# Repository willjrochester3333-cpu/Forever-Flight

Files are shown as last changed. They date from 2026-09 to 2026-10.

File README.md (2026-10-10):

# Forever-Flight — FF-1 *Ember*

A 2 m span autonomous soaring glider for wildfire detection, with a
retractable motor pylon and a retractable energy-recovery turbine.

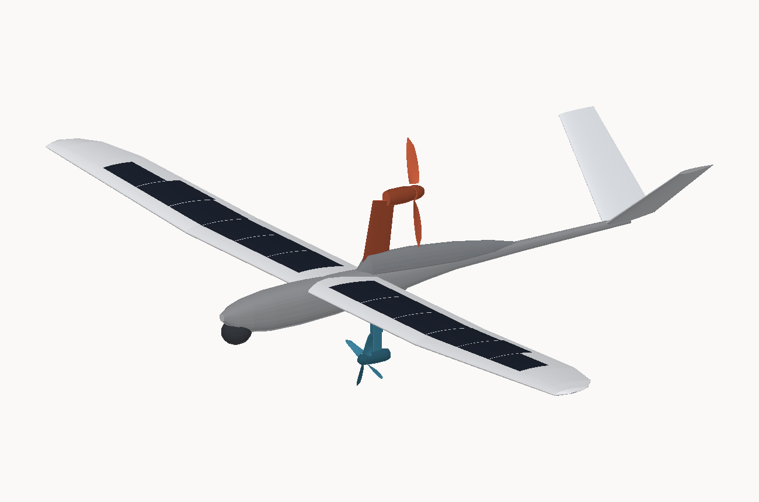
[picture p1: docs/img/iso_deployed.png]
FF-1 Ember


| | |
|---|---|
| Span | 2.00 m |
| MTOW | 1622 g |
| Best glide | L/D 17.6 at 9.5 m/s |
| Minimum sink | 0.51 m/s |
| **Endurance** | **10.0 h** (solar + thermal soaring, 38° N, August) |
| Endurance, battery only | 1.4 h |
| Survey coverage | 10.1 km²/h → 81 km² per sortie |
| Detection floor | ~0.5–1 m² of active flame, clutter-limited |

## What the dynamo actually does

It works. In steady level flight a turbine cannot pay for itself — extracting
power costs more power, and that shows up as drag. But this aircraft doesn't
fly steady level flight. **It soars: it climbs on atmospheric energy and
descends on the turbine, so the source is the air, not the pack. Over that
cycle the output is unambiguously net positive.**

The turbine takes whatever the atmosphere offers beyond what the airframe
needs to stay up. On a good day that's **3.6 W continuous —
46 % of the 7.9 W hotel load — and about
14 Wh over a flight**, a quarter of the pack.

**The catch is storage, not generation.** On a clear day the array has the
pack full by mid-morning, so all of it is spilled. The turbine pays exactly
when the array can't: with one solar string failed it's worth +0.6 h, in heavy
overcast +0.9 h, and with a badly degraded array +4.6 h. That's the argument
for any redundant system — it costs nothing on the days it isn't needed,
because it's stowed.

The deploy rule follows: **only harvest when the pack has room.** On a full
pack the surplus should go into altitude or survey coverage instead.

Full working in [docs/ANALYSIS.md](docs/ANALYSIS.md) §5.5.

## Documents

| | |
|---|---|
| [docs/DESIGN.md](docs/DESIGN.md) | The design plan — configuration, aerodynamics, structure, energy, mechanisms, autonomy, payload, flight test, risks |
| [docs/ANALYSIS.md](docs/ANALYSIS.md) | Every computed number, generated from source |
| [docs/VERTICAL_MAST.md](docs/VERTICAL_MAST.md) | VDM-1 — the telescoping vertical deployment mast and its micro linear actuator |
| [docs/ASSEMBLY.md](docs/ASSEMBLY.md) | Build manual: CG, spars, hinges, throws, balance and the first flight |
| [docs/PRINTING.md](docs/PRINTING.md) | Cutting it into 30 printable parts for a Bambu Lab A2L, and the carbon spar that runs through them |
| [docs/OPTIMISATION.md](docs/OPTIMISATION.md) | Lifting-line optimisation of the wing, and measuring the built mesh against its specification |
| [docs/EDF.md](docs/EDF.md) | The fixed 50 mm EDF installation: nozzle area, inlet lip, and what a duct costs when the fan is off |
| [docs/JETWING.md](docs/JETWING.md) | JW-1 — a swept flying wing in the Jetwing configuration, with the tailless trim solved |
| [docs/VARIANTS.md](docs/VARIANTS.md) | Airframe variants — plans-built glider and nose-motor versions at 2.0 m and 2.5 m |
| [docs/PLANS.md](docs/PLANS.md) | Printable 1:1 build plans, tiled for A4 |
| [docs/FLIGHT_ANALYSIS.md](docs/FLIGHT_ANALYSIS.md) | Flight log analysis — graphs, a fitted drag polar, and predictions from real flight data |
| [docs/BUILD_MANUAL.md](docs/BUILD_MANUAL.md) | Bill of materials and construction sequence |

## The 3D model

```
models/
  ff1_deployed.stl     both pods extended
  ff1_stowed.stl       both pods retracted
  ff1_deployed.obj     named groups, for CAD import
  ff1_stowed.obj
  geometry.json        parametric data, including the solar strip layout
  parts/*.stl          each component separately
```

The assembly STLs are **visual/assembly models**: components interpenetrate at
their joins, so the union is not a closed manifold. Boolean the parts in
Blender or Meshmixer before slicing, or print from `parts/` individually. The
wing meshes on their own are watertight.

Units are millimetres; +X aft with the nose at the origin, +Y starboard, +Z up.

## Building one

```bash
python3 tools/plans.py     # plans/FF-1_plans_A4.pdf -- 22 sheets, print at 100%
```

Full-size foam-prototype templates tiled onto A4: wing, aerofoil sections,
fuselage pod, formers, V-tail. Print at **actual size**, never "fit to page".
See [docs/PLANS.md](docs/PLANS.md).

## Analysing a real flight

```bash
python3 tools/flight_analysis.py YOURLOG.BIN --mass 1.68 --open
```

Reads an ArduPilot log or any CSV and writes an HTML report: flight trace,
measured drag polar against the design curve, energy accounting, and endurance
re-predicted on the measured drag level. See
[docs/FLIGHT_ANALYSIS.md](docs/FLIGHT_ANALYSIS.md). Try it on the bundled
synthetic flight first:

```bash
python3 tools/flight_analysis.py data/example_flight.csv
```

## Regenerating

```bash
python3 tools/build_model.py   # models/
python3 tools/analysis.py      # docs/ANALYSIS.md
python3 tools/render.py        # docs/img/
```

No dependencies — standard library only, Python 3.8+.

`tools/config.py` is the single source of truth. Change a dimension there and
the model, the drawings, the mass budget, the drag polar, the energy budget
and the detection performance all regenerate consistently.

| | |
|---|---|
| `tools/config.py` | Every dimension, mass, efficiency and mission parameter |
| `tools/airfoil.py` | NACA 4-digit generator plus the curvature-limiting "solar flattening" morph |
| `tools/mesh.py` | Triangle mesh kernel, STL and OBJ writers |
| `tools/build_model.py` | Lofted airframe, deployable pods, solar cell layout |
| `tools/analysis.py` | Drag build-up, polar, turbine physics, clear-sky solar model, mission simulation, stability, wing beam, LWIR detection |
| `tools/mast.py` | VDM-1 sizing: stroke, stage count, drive loads, actuator selection, resonance |
| `tools/spar.py` | Shear and bending moment along the span, and the carbon that carries it |
| `tools/optimise.py` | Lifting-line span loading, drag buildup, constrained search over taper, chord and washout |
| `tools/jetwing.py` | Swept flying wing: reflexed section tuned by thin-aerofoil theory, strip-theory trim and CG solve, geometry, export |
| `tools/variants.py` | Builds the plans-based variants (no retractable pods) at any geometric scale |
| `tools/plans.py` | Printable A4 build plans: tiled 1:1 templates, aerofoil sections, formers, DXF |
| `tools/pdf.py` | Minimal vector PDF writer (exact page sizes, so prints come out 1:1) |
| `tools/flightlog.py` | Log readers: ArduPilot .BIN, ArduPilot .log, or any CSV |
| `tools/flight_analysis.py` | Flight report: segmentation, drag-polar fit with bootstrap intervals, endurance re-prediction, HTML + SVG charts |
| `tools/simulate_flight.py` | Synthetic flight log, flown against the design model, for testing the analyser |
| `tools/render.py` | Z-buffered PNG renderer for the three-views |

## Status

Design study with a complete parametric model and a closed analysis. Nothing
has been built or flown. The aerofoil is a geometric mould definition, not a
validated section — see [docs/DESIGN.md](docs/DESIGN.md) §2.1 before cutting
anything.

Flying near an active wildfire without coordination with the incident
commander is dangerous and illegal in most jurisdictions — it grounds the air
tankers. See [docs/DESIGN.md](docs/DESIGN.md) §13.

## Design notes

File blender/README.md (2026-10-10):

# Planes in Blender

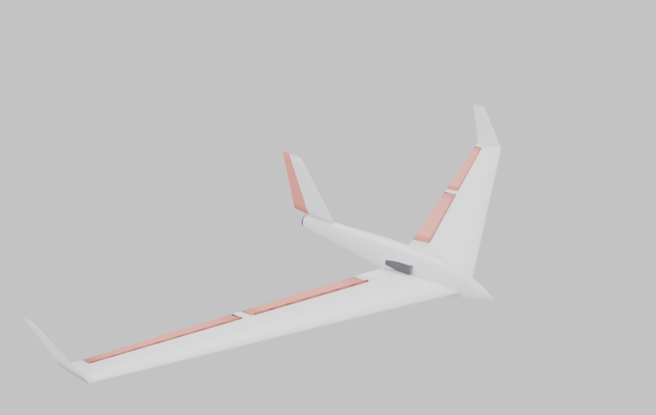
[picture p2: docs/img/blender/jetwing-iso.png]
Jetwing


```
blender/jetwing.py          the swept flying wing (2060 mm BIG WING)
blender/jetwing.blend       ready to open
blender/basic_plane.py      a simple conventional trainer
blender/basic_plane.blend
blender/render_jetwing.py   camera, lights, previews, saves the .blend
blender/render_preview.py   the same, for the trainer
```

## Running

**Any Blender version:** `blender --python blender/jetwing.py`

Opening a `.blend` directly needs **Blender 5.0+**, because the pip `bpy` that
built them is 5.0.1. On 4.x you get a version error — run the `.py` instead,
which works back to 2.8 and gives the identical model.

**No Blender at all:** `pip install bpy && python3 blender/render_jetwing.py`
(Cycles on CPU; EEVEE needs a display.)

## Working control surfaces

Four flaps and a rudder, each a separate object whose origin sits **on its
hinge line**, with the local axis running **along** that line. The hinges are
swept, so they are not parallel to any world axis — the rest frame is stored
on each object as `hinge_origin` / `hinge_basis` / `hinge_axis` (visible in
Blender's Object Properties → Custom Properties) and the deflection is
composed with it:

```python
import jetwing
jetwing.set_controls(flap=40, aileron=-32, rudder=22)   # crow brake + yaw
jetwing.set_controls(elevator=-8)                       # both pairs up
jetwing.set_controls()                                  # neutral
```

`elevator` adds to **both** pairs, which is how a flying wing gets pitch out
of surfaces that are already doing something else.

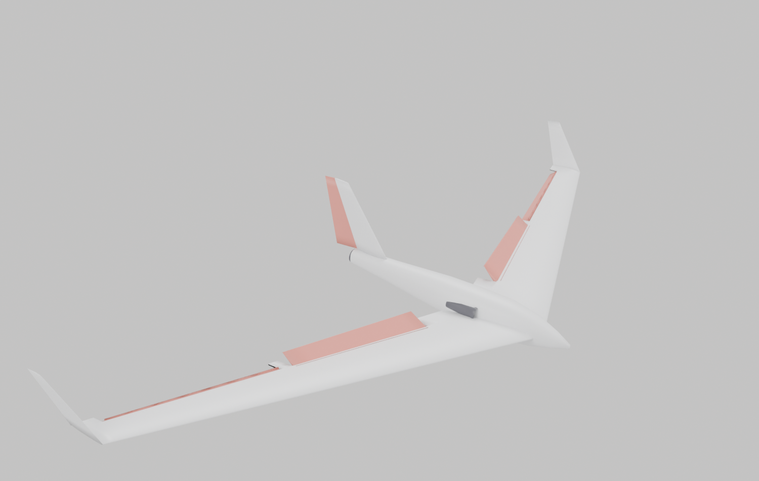
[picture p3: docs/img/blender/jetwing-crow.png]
crow


## Printing it

**`jetwing-parts.blend` — open this one for the parts.** All 30 pieces, each
standing in its print orientation on z = 0, laid out on a grid and labelled
with its name and size, plus an A2L build volume drawn to one side for scale.
The assembled aircraft is in an `Assembled` collection, hidden; tick it back
on in the Outliner to see it whole.

To get a single part out: select it, **File > Export > STL**, tick *Selection
Only*. Or skip Blender entirely and use the ready-made STLs in `print/`.

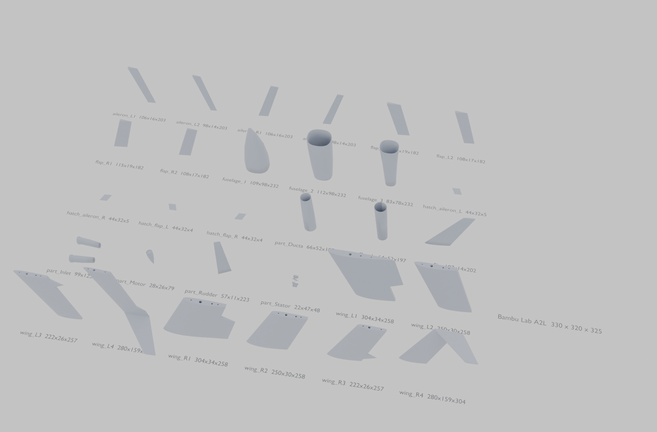
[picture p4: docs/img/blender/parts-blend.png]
parts


`blender/print_parts.py` is what cuts the aircraft into **30 parts, all inside
a Bambu Lab A2L's 330 x 320 x 325 mm and all watertight**, bores the stepped
spar channel, the servo bays, the pushrod guides, the swept loom channel and
the joint dowel holes, and writes `print/*.stl`.

`blender/check_parts.py` then loads every STL back in and audits it: positive
volume, no non-manifold edges, and **no self-intersecting faces**. Run it
before you print. That last test is there because an exact boolean on a
self-intersecting target returns something plausible rather than an error --
it once returned the cutter in place of the part, and a 6 mm tube is
watertight, fits the bed and slices.

See [docs/PRINTING.md](../docs/PRINTING.md) for the carbon sizes and the
assembly order.

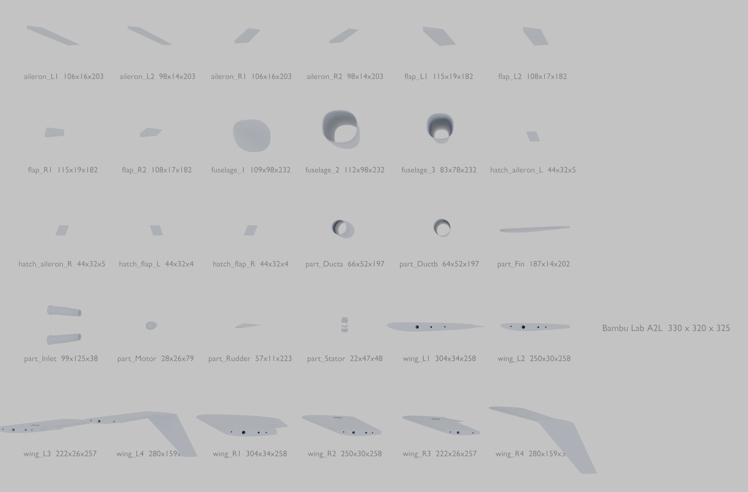
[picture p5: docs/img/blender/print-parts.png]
parts


## Dimensions, and checking them

`blender/measure.py` measures the **evaluated mesh, after modifiers, in world
space** and compares it with the specification, exiting non-zero if anything
is out. `blender/render_dims.py` draws the dimensions onto a plan view, reading
them off the measured geometry rather than off the parameters -- so if the two
ever disagree, the drawing shows the truth.

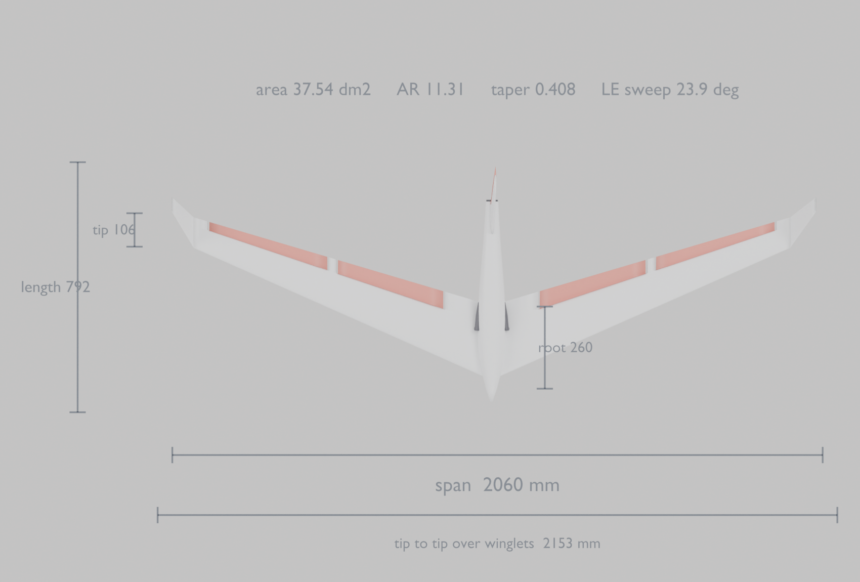
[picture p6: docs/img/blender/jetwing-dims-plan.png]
dimensions


Tip chord and washout are outputs of `tools/optimise.py`, which solves the
span loading by lifting-line theory. See [docs/OPTIMISATION.md](../docs/OPTIMISATION.md).

## The EDF

Fixed 50 mm unit, fully faired, nothing retracting: bellmouth inlets with a
3.1 mm lip radius, a 1.2 deg diffuser, a 12-blade rotor, a 7-vane stator to
take the swirl back out, motor can with a closing tailcone, and a 40.5 mm
converging nozzle. Sizing and the reasoning are in
[docs/EDF.md](../docs/EDF.md); every dimension is an output of
`tools/edf.py`.

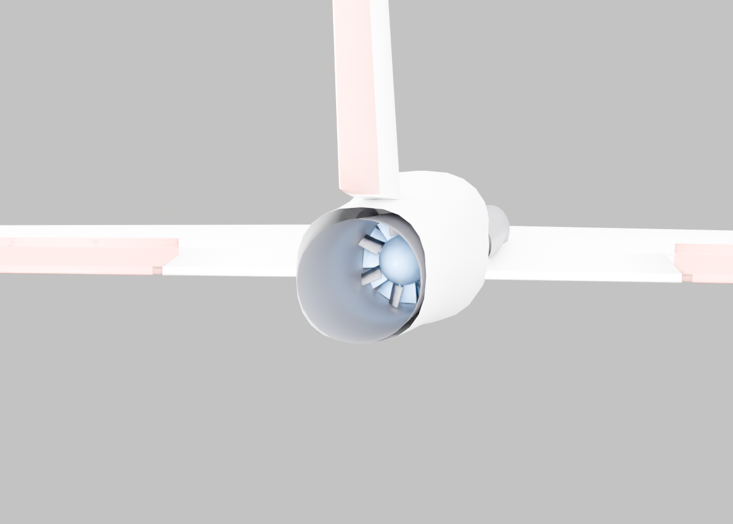
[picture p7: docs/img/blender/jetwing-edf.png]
EDF


## What is copied and what is not

planeprint.com and the mirror of its assembly manual are both blocked by this
session's network policy, so no geometry file was ever available. These
figures are from the published specification, which search did reach:

| | |
|---|---|
| span | 1270 mm standard / **2060 mm BIG WING** ← built here |
| flight weight | 860–1750 g |
| wing loading | 28–48 g/dm² |
| power | EDF 70 mm on 4S, or glider |
| channels | 4/6, **four flaps**, butterfly/crow |
| variants | with or without a steerable rudder; the rudder version has *"integrated vector control"* |
| printing | 200 mm cube, LW-PLA + PLA |

Wing **area** is not published. 36.5 dm² is chosen because it is the one value
that makes all four published numbers land exactly:

```
1022 g -> 28.0 g/dm2        1750 g -> 48.0 g/dm2
```

and it lets both wings share one 260 mm root chord, which a modular kit with a
common fuselage joint has to do.

**Sweep, taper, aerofoil and CG are published nowhere.** Those are designed
from the aerodynamics — a reflexed section with washout so the wing trims
itself without a tailplane — not copied. So this is a faithful model, not a
replica. Real dimensions go straight into the `P` dictionary at the top of
`jetwing.py`.

## Structure

Everything is lofted from parametric sections, so the shape is in the maths
rather than in vertex soup:

| | |
|---|---|
| `section()` | NACA 4-digit camber + a trailing-edge reflex term |
| `chord_at` / `le_at` / `twist_at` | planform and washout at any station |
| `place()` | puts a unit-chord section into 3D at a spanwise station |
| `datum()` | one rotation applied to **vertices**, so fuselage, duct and fin share a frame |
| `hinge_frame()` | world position and axes of a swept hinge line |

`datum()` being applied to vertices rather than to objects is deliberate: a
rotated pod and an unrotated fin drift apart and the fin ends up floating in
mid-air, which is exactly what the first attempt did.

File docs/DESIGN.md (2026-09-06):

# FF-1 *Ember* — design plan

A 2 m span autonomous soaring glider for wildfire detection, with a retractable
motor pylon and a retractable energy-recovery turbine.

Every number quoted here is computed by `tools/analysis.py` from
`tools/config.py`. The full working is in [ANALYSIS.md](ANALYSIS.md).

---

## 0. Read this first — what the dynamo actually does

The brief asks for a turbine-driven dynamo that charges the aircraft to
increase flight time. **It does, and the energy is genuinely free. The
limitation is not generation — it is that on a good day there is nowhere to
put it.**

**Where the energy comes from.** In steady level flight a turbine cannot pay
for itself: extracting P watts costs P/(η_gen·η_rect) watts of shaft power,
and that shaft power is drag. But this aircraft does not fly steady level
flight. It soars. It climbs on atmospheric energy and descends on the turbine,
and across that cycle the source is the air, not the pack. **Over a soaring
cycle the output is unambiguously net positive.**

The sustainable harvest is what the atmosphere offers *beyond* what the
airframe needs to stay up:

```
    c_net = f·(w − s_circle) − (1 − f)·s_glide(v)      net specific climb
    P_surplus = W · c_net                              shaft watts the turbine can take
```

On a good day (3.2 m/s thermals, in usable lift 42 % of the time) that comes
to **3.6 W continuous — 46 % of the
7.9 W hotel load — and about 14 Wh over a
flight, a quarter of the pack's nameplate capacity.** In weaker British
conditions it is 1.3 W. The optimum descent speed is
14 m/s, not the 20–25 m/s the turbine's raw power curve suggests:
rotor power goes as V³, but so does airframe drag, and past about 15 m/s the
airframe eats the surplus faster than the rotor can take it.

**The catch is storage, not generation.**

| Array output | Condition | Turbine off | Turbine on | Gain | Harvest spilled |
|---|---|---|---|---|---|
| 100 % | clear sky, clean array | 10.07 h | 10.07 h | **+0.00 h** | 100 % |
| 55 % | thin overcast | 9.88 h | 9.90 h | **+0.02 h** | 74 % |
| 40 % | one of three strings failed | 9.10 h | 9.71 h | **+0.61 h** | 0 % |
| 30 % | heavy overcast | 7.98 h | 8.86 h | **+0.87 h** | 0 % |
| 20 % | array badly degraded | 2.56 h | 7.18 h | **+4.62 h** | 0 % |

On a clear day the array has the pack full by mid-morning, so **every watt-hour
the turbine makes is spilled**. The energy is real; the tank is full. The
turbine pays exactly when the array cannot — overcast, soiling, a failed
string, low winter sun — and in that band it is worth **hours**.

That is a better reason to carry it than a daily contribution would be. It is
the argument for any redundant system: it costs nothing on the days it is not
needed, because it is stowed. Three jobs:

| Mode | When | Value |
|---|---|---|
| **A — surplus harvesting** | Soaring with lift to spare | 1.3–3.6 W sustained, spilled when the pack is full |
| **B — regenerative descent** | Any commanded descent | Replaces the spoilers the wing would otherwise need |
| **C — emergency power** | Pack or array failure | 8.1 W at 15 m/s against a 7.9 W hotel load — keeps the autopilot and radio alive all the way down |

The deploy rule follows directly, and it is already in §6.1: **only harvest
when the pack has room.** On a full pack the surplus should go into altitude
or airspeed — banked as potential energy, or spent on survey coverage — not
into a turbine with nowhere to send it.

**The eight hours still come mostly from somewhere else.** Solar plus
autonomous thermal soaring gives 10.1 hours. On batteries
alone this aircraft flies for 1.5 hours. The turbine is the margin that makes
a bad day survivable, not the primary mechanism.

---

## 1. Configuration

isometric, pods deployed

Pod-and-boom fuselage, shoulder-mounted three-panel wing, V-tail. Both
deployable pods retract into the fuselage: the motor pylon folds aft into a
dorsal spine, the turbine arm folds forward under the keel.

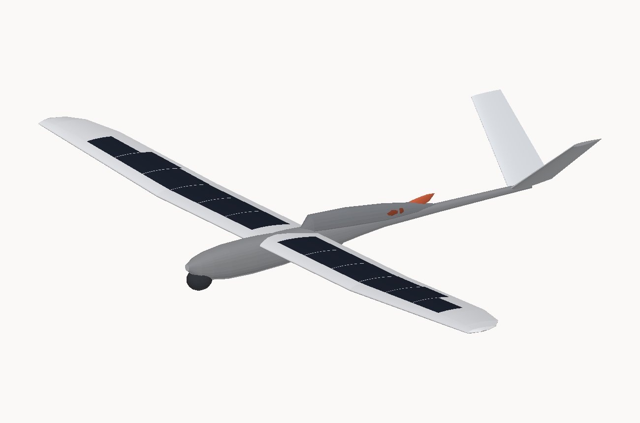
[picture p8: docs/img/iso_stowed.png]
isometric, pods stowed


*Stowed: a clean sailplane. This is the configuration it spends most of the
mission in.*

| | |
|---|---|
| Span | 2.00 m |
| Wing area | 0.3580 m² |
| Aspect ratio | 11.17 |
| Mean aerodynamic chord | 181.8 mm |
| Length overall | 1.19 m |
| MTOW | 1622 g |
| Wing loading | 44.4 N/m² (4.53 kg/m²) |
| Aerofoil | FF-SC1, 9.48 % thick, 2.76 % camber — a solar-flattened SD7037-class section |
| Best glide | **L/D 17.6 at 9.5 m/s** |
| Minimum sink | **0.51 m/s at 9.0 m/s** |
| Stall | 7.79 m/s clean, 7.00 m/s with flap |
| Powered cruise | 16.7 W electrical at 9.5 m/s |
| Climb | 89 W electrical for 2.5 m/s |
| Endurance | 10.0 h (38° N, August), 1.4 h on batteries alone |
| Survey coverage | 10.1 km²/h with 30 % sidelap; 81 km² per sortie |

### 1.1 Why this layout

**Shoulder wing, constant-chord centre panel.** The centre 900 mm is untapered
at 195 mm chord. This is not aerodynamics, it is solar packing: three 41.7 mm
cell strips need 125 mm of usable chord, and only a chord of 179 mm or more
provides it once the leading-edge curvature and the thin trailing edge are
excluded. Outboard of the break the chord tapers to 92 mm and the array drops
to two strips wide.

**V-tail at 38° dihedral.** Two surfaces instead of three saves mass and
wetted area, and — the reason that actually decided it — it keeps the tail
volume out of the way of the deployed turbine's wake and gives the folded
pylon somewhere to go without a fin root in the middle of it. Tail volumes
land at V_h 0.55 and V_v 0.031, both comfortably conventional.

**Sensor turret slung under the nose, not on it.** A ventral ball at
x = 40 mm keeps the fuselage nose free and gives the thermal core a clean
nadir view with no propeller in front of it. It also means Variant N (§8) is
geometrically available.

**Pusher prop on the pylon.** The prop disc sits 79 mm aft of the wing root
trailing edge and 36 mm above the boom at its lowest point. A tractor
installation at the same pylon height would put the blade tips into the wing
trailing edge.

### 1.2 Three-view

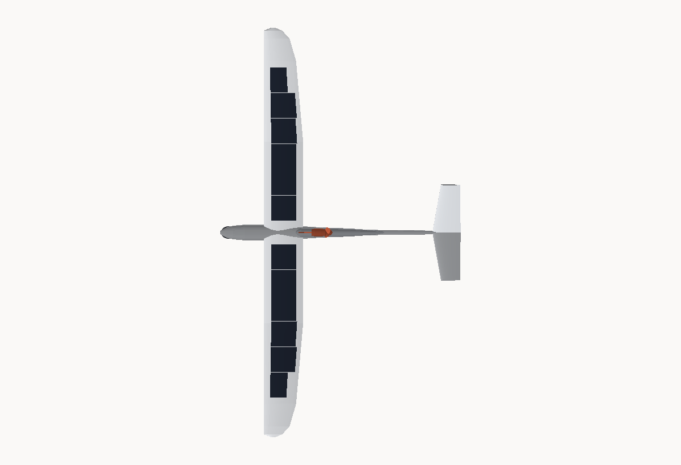
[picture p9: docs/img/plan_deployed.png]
plan

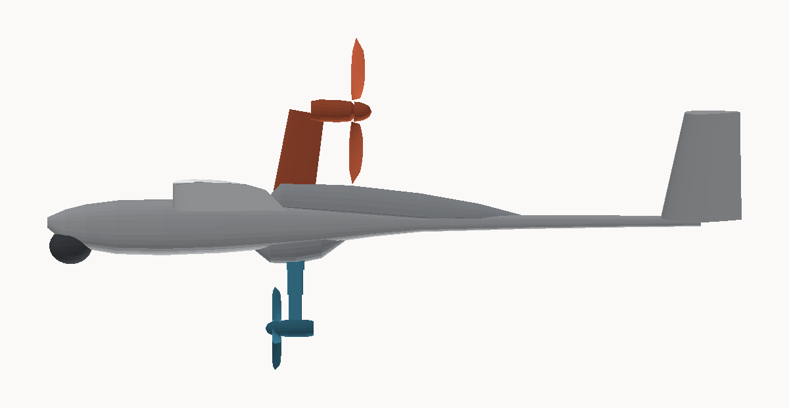
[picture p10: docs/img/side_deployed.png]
side, deployed

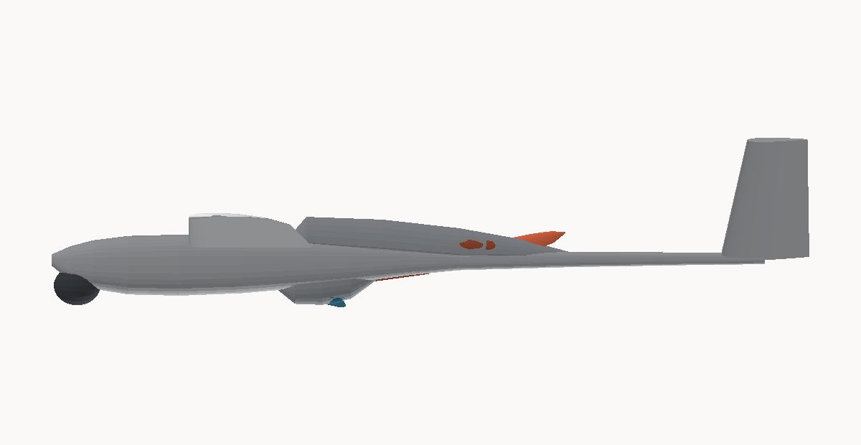
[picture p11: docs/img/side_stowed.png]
side, stowed

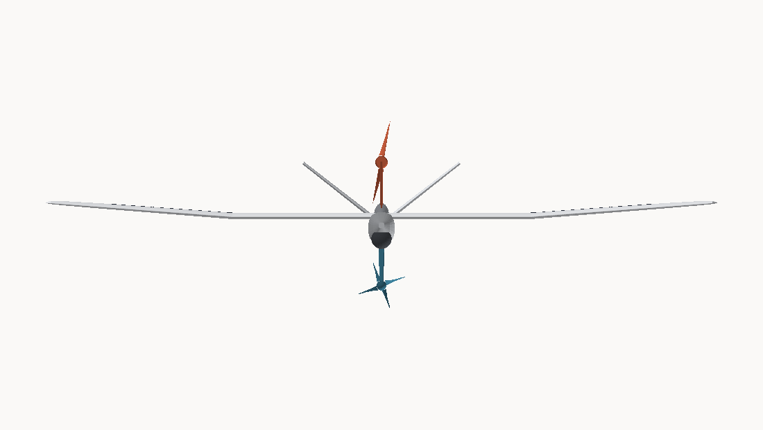
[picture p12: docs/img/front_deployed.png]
front


---

## 2. Aerodynamics

### 2.1 The aerofoil problem

Two requirements fight each other. A good low-Reynolds section at Re ≈ 110 000
wants generous upper-surface curvature to keep the laminar separation bubble
short. A monocrystalline solar cell wants to be flat, because bending it
cracks it.

The resolution is a **curvature-limited morph**. Start from a cambered base
section, then relax the upper surface between 19 % and 90 % chord until the
local radius everywhere exceeds 400 mm. `tools/airfoil.py` does this by
clamped Laplacian smoothing, which can only ever reduce curvature, so it
converges monotonically.

The result, FF-SC1, is 9.48 % thick at 28.1 % chord with 2.76 % camber at
44.8 % — geometrically very close to SD7037 (9.2 % / 2.6 %), which is a good
sign, because SD7037 is a known-good section in exactly this Reynolds range.
The flattening costs about 0.5 points of thickness and 0.2 points of camber
against the unmorphed base.

At R = 400 mm a 165 µm cell sees 0.021 % bending strain, roughly a factor of
seven below the fracture strain of cut monocrystalline silicon.

> **This is a mould definition, not a validated aerofoil.** FF-SC1 exists so
> the 3D model and the plug have exact geometry. Before cutting a mould, put
> SD7037 (or an AG40-series section) through the same morph, run it in
> XFOIL/XFLR5 at Re 90k–160k with N_crit 9, and confirm the drag bucket
> covers C_L 0.4–1.1. Drop the .dat file in `airfoils/`, point
> `WING["airfoil"]["dat_file"]` at it, and the whole model regenerates on the
> real section.

### 2.2 Drag

C_D0 = **0.0247** with both pods stowed, from a component build-up with a
15 % uncertainty margin. The wing profile is 45 % of it; the fuselage, tail
and the two bay fairings make up most of the rest.

Two entries deserve attention because they are self-inflicted:

- **Solar cell steps, 0.0012.** Cell edges and bus ribbons under the
  encapsulation are a surface-roughness penalty on the most important 70 % of
  the wing's upper surface. Flush-bonding the cells into a recess in the skin
  rather than laying them on top is worth roughly half of this.
- **The dorsal spine, 0.0011.** This is the permanent cost of being able to
  swallow the pylon. It is paid on every second of the flight, deployed or not.

At soaring C_L induced drag is 60 % of the total, so parasite-drag increments
are diluted. That is why deploying both pods only costs 6.7 % in sink rate
(§8) — much less than intuition suggests.

### 2.3 Reynolds number

Re at the MAC runs 91 000 at the stall to 180 000 at 15 m/s. This is the
regime where surface finish and transition behaviour decide the drag, not the
planform. Practical consequences:

- Wet-sand and polish the moulded surfaces. A 0.1 mm step at 20 % chord is
  worth more drag than a badly chosen taper ratio.
- Plan for **turbulator tape** at roughly 55–60 % chord on the lower surface
  if flight test shows a drag bucket that is narrower than XFOIL predicts.
  Leave the position to flight test; do not mould it in.
- Do not chase aspect ratio past about 12. The chord gets short, Re falls, and
  section drag rises faster than induced drag falls.

---

## 3. Structure

Carbon/foam wing, moulded pod, tapered carbon boom.

| | |
|---|---|
| Limit load factor | 5 g (ultimate 7.5 g) |
| Root bending moment | 16.9 N·m |
| Spar caps | 9 mm wide, 3 plies of 115 g/m² UD carbon at the root, dropped to 1 ply at 70 % semi-span |
| Root cap stress at limit | 343 MPa (≈ 700 MPa allowable, T700 UD) |
| Root EI | 51 N·m² |
| Tip deflection | 18 mm at 1 g, 91 mm at limit |

**The wing is stiffness-driven, not strength-driven.** The cap laminate is set
by wanting a flat, unstressed array — a flexing wing cracks cells and works
encapsulation seams open — long before it is set by stress. Do not thin the
caps to save the 30 g the stress margin appears to allow.

Wing construction, root to tip:

1. **D-box**: 45/45 biaxial carbon over the leading edge, wrapping to the spar.
   This carries the torsion, which matters because the array's mass is
   distributed and aft of the shear centre.
2. **Spar**: UD caps top and bottom at 30 % chord, separated by a vertical
   shear web of 45/45 glass. Caps are stepped, not tapered by sanding.
3. **Core**: 60 kg/m³ extruded polystyrene or Rohacell, hot-wire cut to the
   FF-SC1 section, relieved for the cell recesses.
4. **Skin**: 25 g/m² glass over the core aft of the spar, then the cell array,
   then the ETFE encapsulation as the outermost layer.
5. **Joiner**: 12 mm pultruded carbon tube in an aluminium sleeve at the
   centre-panel joints, with an anti-rotation pin 40 mm aft.

The three-panel wing exists so the aircraft fits in a 1.1 m case. The centre
panel carries the spar box and both bay structures; the outer panels are plugs.

---

## 4. Energy system

```
   solar array ── 3 strings ──► 3-channel MPPT ──┐
   (34 strips, 11.33 cells)                      │
                                                 ├──► 12 V bus ──► BMS ──► 3S1P 21700
   turbine ──► FOC regen controller ─────────────┤                        (52.8 Wh)
   (150 mm, 4 folding blades)                    │
                                                 └──► 5 V / 3.3 V rails ──► avionics,
   motor ◄── bidirectional ESC ◄──────────────────────                      payload
```

### 4.1 Array

34 strips (11.33 full-cell equivalents) on the wing, 1771 cm² of active cell,
**39.8 W nameplate at STC**. Cells are cut into thirds so the 125 mm dimension
runs *spanwise* — the only curvature a strip has to follow is the 41.7 mm
chordwise one, which is what §2.1 was for.

Installed chain efficiency is **15.5 %**, from 22.5 % cell efficiency after
encapsulation transmission (0.94), cell temperature (0.94), mismatch and
soiling (0.95), MPPT (0.955) and attitude/heading cosine losses (0.86). That
gives 27.5 W at 1000 W/m² on a horizontal wing, peaking around 29.6 W in
flight.

**Three independent strings on three MPPT channels**, not one. A banked turn
puts one wing panel into a different irradiance from the other; with a single
series string the shaded cells drag the whole array down to their current.
Bypass diodes every 7 strips as well.

A V-tail sub-array (+7.0 W STC) is laid out in the model but deliberately
**excluded from the energy budget** — the panels sit at 38° dihedral, their
cosine losses are much worse, and the budget closes without them. Treat it as
a growth item.

### 4.2 Pack

3S1P 21700, 52.8 Wh nameplate, **38.9 Wh usable** after 85 % depth of
discharge and a 6 Wh approach reserve.

Cell selection is set by the **climb** case, not by capacity: 89 W at 11.1 V
is 8.0 A, so cells must be rated ≥ 10 A continuous. The tempting
high-capacity, low-current 21700s are the wrong part — take the 5.0 Ah /
25 A cell over the 5.0 Ah / 7 A one.

### 4.3 Loads

Hotel load is **7.9 W**; powered cruise adds 15.1 W. So on the ground the
avionics and payload are 34 % of the powered demand and 100 % of the soaring
demand.

**On this aircraft a watt saved in avionics is worth more than a drag count.**
Concretely: duty-cycling the edge compute from 50 % to 25 % saves 1.2 W, which
is worth more endurance than a 15 % reduction in C_D0. Design the detection
pipeline around that — wake the compute board on a hardware threshold from the
thermal core, do not run inference continuously.

---

## 5. Motor installation

| | |
|---|---|
| Type | Retractable dorsal pylon, pusher |
| Pivot | x = 400 mm, on the fuselage deck |
| Pylon | 190 mm, 74 mm chord, 12 % symmetric section |
| Deployed | 80° from the deck; hub at x = 489 mm, z = +197 mm |
| Stowed | 5°; nacelle and folded blades lie in the dorsal spine to x = 772 mm |
| Motor | Outrunner, ~500 Kv on 3S, 52 g |
| Prop | 10 × 6 folding, 254 mm |
| Deployment penalty | ΔC_D0 0.0025 |

**Mechanism.** A four-bar linkage driven by a metal-gear micro servo through a
3:1 bellcrank, with an **over-centre lock at full deployment** so that in
flight the aerodynamic and thrust loads are reacted by the linkage geometry
and not by the servo. Deployment takes about 1.2 s. Bay doors are cammed off
the linkage itself — no second servo, and the doors cannot be open when the
pylon is not.

**Clearances** (verified by `tools/build_model.py`, which will refuse to
produce a model that violates them):
- Prop disc 79 mm aft of the wing root trailing edge.
- Lowest blade tip 36 mm above the boom.
- Stowed blades end at x = 772 mm; the spine runs to x = 820 mm.

**Thrust line** is 197 mm above the datum and slightly above the drag line, so
power-on pitches the nose down a little. 1.5° of down-thrust is built in to
reduce the trim change; expect to fine-tune this on the first flights.

---

## 6. Energy-recovery turbine

| | |
|---|---|
| Rotor | 150 mm, 4 folding blades, solidity 0.31 |
| Design point | λ = 2.5, C_p 0.36 |
| Generator | Low-Kv outrunner, ~380 Kv, 44 g |
| Controller | Field-oriented regen controller into the 12 V bus |
| **Mounting** | **VDM-1 vertical telescoping mast** — see [VERTICAL_MAST.md](VERTICAL_MAST.md) |
| Station | x = 425 mm, on the wing trailing-edge bulkhead |
| Stroke | 128 mm straight down, from 42.7 mm of micro-linear-actuator travel |
| Deployed | Nacelle at z = −175 mm; disc from −100 to −250 mm |
| Output | 8.1 W at 15 m/s, 19.3 W at 20 m/s, 37.7 W at 25 m/s |
| Deployment penalty | ΔC_D0 0.0033, plus the extraction drag |

**The rotor was resized during design.** A 110 mm rotor produced 1.3 W at
cruise speed and was not worth carrying. Power goes as R² and as V³, so the
fix was a bigger rotor and a rule that it only runs fast. Folding blades let a
150 mm rotor stow in a shallow ventral bay.

**The mounting changed too.** The original swing arm moved the pod 157 mm aft
on deployment, shifting the CG +12.9 mm — 7.1 % of mean chord, taking static
margin from 20 % down to 13 % at the moment the turbine extends. A mast that
only translates vertically shifts it by nothing, keeps the rotor axis aligned
with the flow through the whole travel, and makes deployment depth a
continuous variable. It costs +90 g and 3.4 % of sink rate. The full sizing,
including why 128 mm of travel has to telescope to fit inside a 73 mm deep
fuselage, is in [VERTICAL_MAST.md](VERTICAL_MAST.md).

### 6.1 Control law

This is the part that keeps the turbine from being a net loss. The turbine may
engage **only** when one of these is true:

```
A.  ceiling_hold:   altitude ≥ soar_ceiling
                AND vario_filtered ≥ 2.5 m/s
                AND airspeed ≥ 16 m/s

B.  regen_descent:  descent commanded by the mission planner
                AND altitude ≥ 150 m AGL
                AND state_of_charge < 92 %

C.  emergency:      bus_voltage < 10.2 V  OR  mppt_fault  OR  pack_fault
```

and it must disengage, and the arm must retract, when **any** of these is true:

```
    altitude < 25 m AGL          (mandatory — the rotor hangs 216 mm below
                                  the keel and there is no landing gear)
    airspeed < 14 m/s            (below this it costs more than it makes)
    state_of_charge > 97 %
    bank angle > 45° for > 3 s   (asymmetric inflow, blade root loads)
    any deployment fault
    airspeed > 20 m/s            (mast load limit -- see VERTICAL_MAST.md §7)
```

Implement the interlocks in the flight controller's Lua scripting layer, and
implement the 25 m AGL retract **as a hardware failsafe as well** — a servo
release on a discrete output, independent of the scripting engine.

### 6.2 What it actually returns

| Day | Thermal | In lift | Sustainable harvest |
|---|---|---|---|
| Weak, N. Europe | 2.2 m/s | 34 % | 1.3 W |
| Good, S. Europe | 3.2 m/s | 42 % | 3.6 W |
| Strong | 4.0 m/s | 45 % | 5.2 W |

Full grid in [ANALYSIS.md](ANALYSIS.md) §5.5. Two things fall out of it that
are not obvious:

**On good days the rotor is the limit, not the atmosphere.** A 150 mm rotor
cannot absorb everything a strong day offers at the optimum descent speed.
Going to 175 mm buys about 0.7 W more harvest and 3 W more in Mode C, at the
cost of 18 mm more mast stroke (146 mm instead of 128) and the mass that comes
with it. The baseline stays at 150 mm because the extra is only available on
days when the pack is full anyway — but if the aircraft is ever re-scoped for
overcast operation, size the rotor up.

**Descend slowly.** The optimum is 14 m/s. Diving at 25 m/s
extracts more instantaneous power but wastes far more of the surplus in
airframe drag, and it burns the altitude band faster.

## 7. Avionics and autonomy

| Function | Specification |
|---|---|
| Flight controller | ArduPlane on an F405/H743-class wing board, with airspeed and a good baro |
| Soaring | **ArduSoar** (`SOAR_ENABLE`), variometer-based thermal detection with Reichmann centring on an EKF thermal estimate |
| Navigation | GNSS with SBAS, magnetometer, airspeed (essential — the soaring controller needs energy rate, not just baro) |
| Link | 868/915 MHz LoRa telemetry for BVLOS command and hotspot reporting; a 2.4 GHz control link for the test phase |
| Payload compute | Low-power SBC, event-triggered, not free-running |

**Autonomous thermal soaring is not optional here.** The 8-hour requirement
closes on solar alone in good conditions, but the margin that absorbs a hazy
day, a cool morning or a dirty array comes from thermals. ArduSoar is mature,
in-tree and flight-proven on aircraft of this class; use it rather than
writing a soaring controller.

Key parameters to set: `SOAR_VSPEED` (climb rate to trigger thermalling — start
at 0.7 m/s), `SOAR_ALT_MIN` / `SOAR_ALT_MAX` for the soaring band (250–900 m
here), and `SOAR_POLAR_*` for the sink polar in §2 so the speed-to-fly logic
is right.

The survey pattern and the soaring controller must share an altitude budget.
The sensible architecture is: fly the survey lawnmower pattern as the default,
let ArduSoar interrupt it to climb when it finds lift, and resume the pattern
at the interruption point. Do not try to soar and survey simultaneously —
banking hard in a thermal wrecks the sensor geometry anyway.

---

## 8. Wildfire payload

| | |
|---|---|
| Thermal | LWIR radiometric microbolometer, 160 × 120, 57° HFOV, 50 mK NETD, 8–14 µm |
| Visible | Rolling-shutter module for smoke-plume cross-checking and geolocation |
| Survey altitude | 400 m AGL |
| Ground swath | 434 m |
| Ground sample distance | 2.71 m/pixel (7.4 m² per pixel) |
| Coverage | 10.4 km²/h with 30 % sidelap → **83 km² per 8 h sortie** |

### 8.1 Sub-pixel detection

A fire much smaller than one pixel still raises that pixel's apparent
temperature, because radiant exitance goes as T⁴. Computed properly — with the
Planck integral over the 8–14 µm band, which captures only 17 % of an 800 K
flame's emission against 38 % of the background's, so LWIR is the
*unfavourable* band here:

| Flame area | Pixel fill | Apparent pixel T | ΔT | ΔT / NETD |
|---|---|---|---|---|
| 0.05 m² | 0.7 % | 36.1 °C | +9.1 K | 182× |
| 0.10 m² | 1.4 % | 44.5 °C | +17.5 K | 350× |
| 0.50 m² | 6.8 % | 98.3 °C | +71.3 K | 1425× |
| 1.00 m² | 13.6 % | 148.9 °C | +121.9 K | 2437× |
| 4.00 m² | 54.3 % | 353.3 °C | +326.3 K | 6527× |

**The sensor is not the limit — clutter is.** Sun-baked rock, dark soil and
asphalt reach 55–70 °C on a summer afternoon, which is +28 to +43 K. Anything
below that is indistinguishable from hot ground in a single frame. The
realistic single-frame detection floor is **0.5–1 m² of active flame**, not
the 0.05 m² the raw NETD implies.

Getting below that needs the contextual approach the MODIS and VIIRS fire
products use, and it is worth implementing properly:

1. **Contextual thresholding** — compare each candidate pixel against the mean
   and standard deviation of a background window around it, excluding other
   candidates. A pixel is a candidate when it exceeds background by both an
   absolute threshold and 4σ of its own neighbourhood.
2. **Temporal persistence** — the aircraft moves, so a real hotspot is seen
   from several angles over several seconds while a sun-glint is not. Require
   3 detections in 5 frames after geolocation.
3. **Visible cross-check** — a plume is the highest-confidence discriminator
   available and costs nothing extra to look for.
4. **Solar geometry masking** — reject candidates whose position relative to
   the sun vector makes specular reflection likely.

Report hotspots as geolocated candidates with a confidence score over the LoRa
link. Do not attempt to make the aircraft the arbiter of what is a fire.

---

## 9. Mass, balance and deployment effects

MTOW **1622 g**, ±35 g RSS on the itemised total, with a 6 % growth allowance
already included. The energy system (pack, cells, encapsulation, MPPT) is the
single biggest group at 419 g — 27 % of the aircraft.

| | |
|---|---|
| Neutral point | 54.2 % MAC |
| **CG target** | **34.2 % MAC = 277 mm aft of the nose** (20 % static margin) |
| CG forward limit | 26.2 % MAC |
| CG aft limit | 42.2 % MAC |

The battery sits on a **sliding tray** at x = 160–235 mm precisely so the CG
can be trimmed without ballast; 212 g of pack moving 20 mm shifts the CG about
2.6 mm, or 1.4 % MAC.

Deploying either pod moves mass aft and away from the datum. Both are aft of
the CG, so both deployments trim slightly nose-up and both are mildly
stabilising in yaw. Trim the autopilot for the stowed case. **The deployment
transient, not the trimmed state, is what to watch on the first flights** —
schedule deployments at level cruise, never in a turn or on approach.

---

## 10. Trade study — is the deployable pylon the right answer?

| Option | MTOW | C_D0 stowed | L/D | sink | ΔC_D0 running |
|---|---|---|---|---|---|
| Deployable dorsal pylon (baseline, as requested) | 1622 g | 0.0247 | 17.6 | 0.540 m/s | 0.0025 |
| Nose folding prop (Variant N) | 1551 g | 0.0231 | 18.2 | 0.516 m/s | 0.0003 |

**Variant N is 71 g lighter, has 4.5 % less sink, and has no mechanism to
jam** — it deletes the pylon, its actuator, its doors and the dorsal spine
that swallows it. Because the sensor turret is ventral, the nose is free for a
folding prop.

The dorsal pylon buys three things in exchange:

- the prop disc is clear of the ground on a belly landing;
- the nose stays available if the ventral turret is ever outgrown;
- thrust acts above the drag line, so power changes pitch the aircraft less.

**The baseline keeps the pylon because it is what the brief asked for, and the
penalty is real but small.** If endurance is the only thing that matters,
build Variant N. The turbine's retraction is not in question either way — it
has to stow for landing regardless.

And for completeness: the whole retraction argument is worth less than
intuition suggests. Flying with *both* pods hanging out costs only 6.7 % in
sink rate, because at soaring C_L induced drag dominates. Retraction is right,
but it is not transformative.

---

## 11. Flight test plan

Do not fly the full system on day one. Six phases, each with a go/no-go:

| Phase | Configuration | Objective | Go criterion |
|---|---|---|---|
| **1. Glide** | No motor, no turbine, ballast to MTOW, bays faired over | Trim, CG, stall behaviour, measured sink polar | Measured L/D within 15 % of 17.6 |
| **2. Power** | + motor pylon, deployed and pinned | Climb rate, thrust line, prop efficiency | ≥ 2.0 m/s climb at ≤ 95 W |
| **3. Retraction** | + pylon actuation | Deployment/retraction cycles at altitude, transient magnitude | 50 cycles, no jam, transient < 5° pitch |
| **4. Soaring** | + ArduSoar enabled | Autonomous thermal detection and centring | Net altitude gain in a 30 min sortie |
| **5. Turbine** | + turbine, tethered ground run first | Power curve vs airspeed, drag penalty, 25 m failsafe | Measured P(V) within 25 % of §6; failsafe retracts every time |
| **6. Endurance** | Full system | 8 h sortie with payload | Lands with ≥ 15 % SoC |

Instrument phase 1 properly. A measured sink polar from a GPS-logged series of
stabilised glides at 7.5, 8.5, 9.5, 11 and 13 m/s is the single most valuable
data set in the programme — it validates or destroys the C_D0 build-up, and
every energy number downstream depends on it.

**Phase 5 is the dangerous one.** Ground-run the turbine on a vehicle-mounted
rig first, at 15 and 20 m/s, with the arm restrained. A blade shed at 6400 rpm
is a serious projectile. Balance the rotor, proof-load the folding hinges to
3× the centrifugal load, and fly the first airborne test over open ground.

---

## 12. Risks

| Risk | Effect | Mitigation |
|---|---|---|
| **Turbine deployed on landing** | Destroys the rotor, arm and probably the keel | Hardware failsafe at 25 m AGL, independent of the flight controller scripting; belly skid aft of the bay |
| **Cell cracking in service** | Progressive array output loss, hard to diagnose | Curvature-limited section (§2.1); electroluminescence-image the array before and after the first 10 flights |
| **Pylon jams deployed** | 6.7 % sink penalty, still flyable | Over-centre lock with a manual release; the aircraft must remain airworthy with both pods stuck out — it is, see §10 |
| **Optimistic prop efficiency** | 0.68 is a hopeful figure at this Reynolds number | Phase 2 measures it. If it comes in at 0.60, cruise power rises to 17 W and endurance falls about 8 % — the budget absorbs it |
| **Hotel load growth** | Directly erodes endurance | 7.9 W is a budget, not an estimate. Meter each rail on the bench and hold each subsystem to its line |
| **Thermal detection false alarms** | Operationally worse than a miss | Contextual + temporal + visible cross-check (§8.1); report confidence, never a binary |
| **Overcast or winter operation** | Endurance falls to roughly the battery-only 1.4 h | Not a design fix. This is a fair-weather, fire-season aircraft. State it in the ConOps |

---

## 13. Regulatory and safety

Two things need saying plainly.

**This is a real aircraft and the rules apply.** At 1.5 kg it sits in the sub-2 kg
class in most jurisdictions, but the mission — long endurance, beyond visual
line of sight, over remote terrain — is exactly the profile that requires
specific authorisation rather than the open/recreational category. In the UK
that means a CAA Operational Authorisation; in the EU, a Specific-category
authorisation under an SORA; in the US, a Part 107 BVLOS waiver. Rules change,
and my information has a cutoff — check the current requirements with your
national authority before the first BVLOS flight, not after.

**Never fly this near an actual active wildfire without explicit coordination
with the incident commander.** Firefighting aircraft operate low and fast in
smoke, and airspace over active incidents is restricted precisely because an
unexpected drone grounds the air tankers. A UAS sighting can halt aerial
firefighting for hours. The useful role for an aircraft like this is
**detection over unburnt ground during high fire-danger periods**, upstream of
any incident — not over a fire that already has a response.

---

## 14. Where to go next

1. Run SD7037 through the flattening morph and validate it in XFOIL. Replace
   FF-SC1 in `config.py`.
2. Build a one-panel wing section and electroluminescence-image the array
   before and after a bend test to confirm the 400 mm radius limit.
3. Bench the hotel load. It is the number most likely to be wrong and it hits
   endurance hardest.
4. Build the phase-1 glider. Everything else is refinement of a shape that has
   to fly well first.

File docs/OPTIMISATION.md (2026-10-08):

# Optimising the wing, and proving the model matches

```
python3 tools/optimise.py       the search
python3 blender/measure.py      measure the built mesh against the spec
python3 blender/render_dims.py  dimensioned views
```

## What was wrong

The wing had a **94.4 mm tip chord**. At best-glide speed that puts the
outboard sections at **Reynolds 48,700** — below about 55,000 a low-Re
aerofoil's drag rises sharply and it stops reaching the lift coefficient you
designed around. The quoted L/D of 19.6 was a number the aircraft could not
actually have delivered.

Nothing else was badly wrong. Everything the optimiser changed, it changed to
fix that one thing.

## How the search works

Induced drag is most of the drag of a high-aspect-ratio wing at soaring
speeds, and it depends on **how lift is spread across the span** — which is
set by taper and washout. `CL²/(π·AR·e)` with a guessed `e` cannot see that,
so it cannot optimise it; it would just say "more span".

So the span loading is solved by lifting-line theory:

```
y = -(b/2)cos(th)        Gamma(th) = 2bV * sum A_n sin(n th)

sum A_n sin(n th) [ n.mu + sin th ] = mu sin th (alpha - alpha_L0 + twist)

CL = pi.AR.A1      CDi = pi.AR. sum n.A_n^2      e = A1^2 / sum n.A_n^2
```

Span efficiency comes out as an **output of the planform** rather than an
assumption about it, and the same coefficients give the local lift coefficient
at every station — which is what the tip-stall constraint needs.

Validated against known results: `e` = 0.937 for a rectangular wing, 0.979 at
taper 0.45 (the textbook optimum is 0.35–0.45), and washout costs `e` exactly
as it should (−5° drops it to 0.73).

The system matrix depends only on the planform, and the right-hand side is
linear in angle of attack — so it is factored **once** per geometry and every
angle afterwards is a vector combination. That is a 34× speedup and it is the
only reason a three-variable search finishes in a minute.

## What it found

| design | taper | root | tip | washout | AR | area | L/D | sink | Re tip |
|---|---|---|---|---|---|---|---|---|---|
| before | 0.363 | 260 | 94.4 | −2.20 | 11.63 | 36.50 | 19.59 | 0.367 | **48,700 ✗** |
| max L/D, root free | 0.554 | 193 | 106.9 | −2.71 | 13.74 | 30.89 | **20.39** | 0.369 | 55,100 |
| max L/D, root 260 | 0.410 | 260 | 106.6 | −0.34 | 11.24 | 37.76 | 19.47 | 0.373 | 55,700 |
| min sink, root free | 0.476 | 227 | 108.1 | −2.25 | 12.30 | 34.51 | 19.87 | **0.366** | 55,100 |
| **chosen** | **0.408** | **260** | **106.1** | **−1.98** | **11.31** | **37.5** | 19.45 | 0.367 | **55,700** |

**Every optimum lands the tip at 106–108 mm.** That is the Reynolds constraint
binding, in all four searches, whatever the objective. It is the only thing
the wing actually needed.

### Why the chosen one

- **Root stays at 260 mm.** Letting it fall to 193 mm buys +4.8% L/D, but it
  breaks the shared joint with the standard wing. That is a kit-architecture
  decision, not an optimiser's call.
- **Minimum sink, not maximum L/D.** They are nearly the same design here
  (L/D 19.45 vs 19.47), but the max-L/D variant does it with −0.34° of
  washout — almost none. On a swept wing that is thin tip-stall insurance for
  0.1% of glide. −1.98° keeps the margin and gives better sink.
- **Tip loaded to 0.69 of peak**, with the peak well inboard, so it stalls at
  the root first — which on a swept wing is the difference between a recovery
  and a pitch-up.

The headline number went *down*, 19.59 → 19.45. That is honest arithmetic: the
old figure assumed a tip working at a Reynolds number it was not working at.
19.45 is a number the aircraft can have.

## Measuring what was actually built

Every dimension is a number in a dictionary. That is not the same as the model
*having* it — a rotation in the wrong frame, a mirror about the wrong object,
a loft that drops a section, and the model quietly disagrees with its own
specification. Both of those have already happened in this file's history.

So `blender/measure.py` measures the **evaluated geometry, after modifiers, in
world space** and compares:

```
  dimension                    measured  specified     error
  wing span                     2060.00    2060.00     +0.00
  root chord                     260.00     260.00     +0.00
  tip chord                      106.05     106.10     -0.05
  LE sweep                        23.91      24.00     -0.09
  dihedral                         1.86       2.00     -0.14
  wing area (gaps deducted)       37.54      37.49     +0.05
  nozzle exit diameter            40.50      40.50     +0.00
  fan diameter                    48.60      48.60     -0.00

  aspect ratio  11.31    taper 0.408
  built mass 1121 g -> wing loading 29.9 g/dm2   (published envelope 28-48)

  ALL DIMENSIONS WITHIN TOLERANCE
```

It exits non-zero if anything is out, so it works as a check rather than a
report.

Three things it caught while being written, all of them errors in the
*measuring* rather than the model — which is the point of measuring from the
mesh instead of trusting a formula:

- **Span read 2152.7 mm.** Correct — that is over the winglets, which cant
  outboard past the tip. Wing span and tip-to-tip are now separate rows.
- **Area read 6.7 dm².** Integrating over fixed spanwise bands finds nothing,
  because a lofted mesh only has vertices where a section was placed. Areas
  now come from projecting every polygon.
- **Area then read 29.6 dm².** The flaps and ailerons are separate objects,
  cut out of the wing so they can hinge, so "Wing" alone is missing a quarter
  of the chord over three quarters of the span.

The remaining 0.4% is the **hinge gaps** — eight 3 mm gaps at the ends of four
control surfaces. Rather than widen the tolerance to hide it, the specified
area has the gap deduction computed into it, so the comparison stays exact.

## Dimensions on the model

`blender/render_dims.py` writes a `Dimensions` collection — leader lines with
end ticks and text labels for span, root chord, tip chord, overall length,
area, aspect ratio and sweep. The numbers are read off the **measured**
geometry, not off the parameters, so if the two ever disagree the drawing
shows the truth.

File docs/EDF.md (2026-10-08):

# The 50 mm EDF installation

Fixed. Nothing retracts, nothing folds, nothing protrudes. The whole shape is
arranged to make that cost as small as it can be.

EDF

Run the sizing: `python3 tools/edf.py`
Build the model: `blender --python blender/jetwing.py`

## The unit

| | |
|---|---|
| fan | 50 mm, 12 blades, QF2611 5000KV, 9N6P |
| mass | 109 g complete (motor alone 76 g) |
| rating | 550 W / 45 A maximum continuous |
| quoted | 950 g static at 12.6 V, 45 A, 567 W |

12.6 V is a **full 3S pack, not 4S**. On 4S the same 45 A would be 666 W, past
the 550 W rating — so on 4S this unit is *power* limited, not voltage limited.
4S buys lower current, cooler running and thinner wiring, not much more thrust.

My duct model gives 915 g static against their 950 g claim on the same power,
and 806 g on a realistic fan efficiency. Call it **800 g**.

## The number that governs everything

At 16 m/s the fan throws a **72 m/s jet**. That is 4.5× flight speed, and
propulsive efficiency is what is left over:

```
eta_Froude = 2V / (V + Ve) = 2(16) / (16 + 72) = 36.4%
```

With fan and motor losses on top, **22.6%**. That is not a defect in the
installation — it is what a 50 mm fan on a slow aircraft *is*. A 70 mm fan,
which is what the kit calls for, moves 2× the air at a much lower jet speed
for the same thrust, and that is where its efficiency comes from.

Everything below is about not making it worse.

## Design choices, and why

**Nozzle at 0.90 × fan swept area → 40.5 mm.** Exit area is the biggest lever
there is. Opening it gives a slower, fatter jet: more thrust *and* better
efficiency.

| Ae/FSA | dia | thrust | jet | η_p |
|---|---|---|---|---|
| 0.80 | 38.2 | 628 g | 74.7 | 21.9% |
| **0.90** | **40.5** | **648 g** | **72.0** | **22.6%** |
| 1.00 | 42.7 | 667 g | 69.6 | 23.2% |

It looks like you should open it all the way. You cannot: past about 1.00 the
fan unloads, overspeeds and stalls its own blades. 0.90 is the standard pick
and it is what is built.

**Bellmouth inlets, 3.1 mm lip radius.** The duct swallows 114 g/s. At 16 m/s
that is a free-stream tube 3.9× the inlet area, so flow accelerates *in* and
nothing spills — spillage would only start above 62 m/s, which this aircraft
never sees. But inlet velocity is 62 m/s, so the lip has to turn nearly still
air very hard. A sharp lip separates right there, and that is where cheap
installations quietly lose 10–20% of their thrust. The lip is rounded to 10%
of inlet diameter.

**Diffuser half-angle 1.2°, nozzle half-angle 3.0°.** Above about 7° a
diffuser separates and you lose the pressure recovery the duct exists for.
1.2° is very safe. Converging sections are always safe.

**Seven stator vanes against twelve rotor blades.** The rotor leaves swirl in
the jet — rotational energy you have already paid for and get no thrust from.
The stator straightens it out. Seven is prime against twelve so blade passing
never lines up into a tone.

**A closing tailcone behind the motor.** A motor can that just stops leaves a
separated base, which is pure drag inside your own duct.

## What it costs when the fan is off

This is the number that decides a fixed installation on a soaring aircraft,
because gliding is most of the flight:

| | freewheeling | braked |
|---|---|---|
| 10 m/s | 0.033 N | 0.046 N |
| 14 m/s | 0.064 N | 0.090 N |
| 18 m/s | 0.106 N | 0.149 N |

At 14 m/s the aircraft's total drag is roughly 0.6 N, so a freewheeling duct
is about **10% of it** and a braked one about 15%.

**Set the ESC to coast, not brake.** A stopped fan is a flat plate across the
duct; a freewheeling one still passes air. It is a menu setting and it is
worth a third of the duct's cold drag.

## Full output

```
== 50 mm EDF installation, designed for cruise at 16 m/s ==

As drawn: 648 g thrust, jet 72.0 m/s, propulsive efficiency 22.6%
  ideal (Froude) ceiling at that jet speed is 36.4% -- the fan is small, so the jet
  overshoots flight speed 4.5x and most of the power goes into the air, not the aircraft.

NOZZLE AREA, the biggest lever
  Ae/FSA   dia    thrust    jet    eta_p   Froude
   0.80    38.2    628 g   74.7   21.9%   35.3%
   0.85    39.4    639 g   73.3   22.2%   35.8%
   0.90    40.5    648 g   72.0   22.6%   36.4%
   0.95    41.6    658 g   70.7   22.9%   36.9%
   1.00    42.7    667 g   69.6   23.2%   37.4%
   1.05    43.8    675 g   68.5   23.5%   37.9%
  Opening the nozzle trades static thrust for efficiency. 0.90 is
  the usual compromise and is what is built; going past 1.00 unloads
  the fan into blade stall, so it is not free.

INLET
  swallows 114 g/s; at 16 m/s that is a free-stream tube 3.9x the inlet area,
  so the flow accelerates IN and nothing spills. Spillage would only
  start above 62 m/s, which this aircraft never sees.
  inlet velocity 62 m/s -> the lip has to turn still air
  hard, so round it to 3.1 mm. A sharp lip separates and
  that is where cheap installations lose 10-20% of their thrust.

INTERNAL ANGLES
  two 30.9 mm inlets -> 43.8 mm equivalent -> 50 mm fan
  diffuser half-angle 1.2 deg (keep under 7, or it separates)
  nozzle half-angle 3.0 deg, converging, which is always safe

WHAT IT COSTS WHEN THE FAN IS OFF
  10.0 m/s: freewheeling 0.033 N, braked 0.046 N
  14.0 m/s: freewheeling 0.064 N, braked 0.090 N
  18.0 m/s: freewheeling 0.106 N, braked 0.149 N
  A soaring aircraft glides far more than it motors, so this is the
  number that decides the installation. LET THE FAN FREEWHEEL --
  set the ESC to coast, not brake. A stopped fan is a flat plate.
```

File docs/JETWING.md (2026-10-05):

# JW-1 — a swept flying wing in the Jetwing configuration

```bash
python3 tools/jetwing.py
```

Writes `models/jetwing/jetwing-1500.stl` / `.obj` (the larger wing) and
`jetwing-1200` (standard), plus renders.

## What this is, and what it is not

**It is not a copy of PlanePrint's Jetwing.** `www.planeprint.com` is blocked
by this session's network egress policy — the proxy returns 403 on CONNECT —
so none of their published dimensions, weights, motor sizes or CG figures were
available, and a single photograph does not give geometry. Reproducing a
commercial model's STL would not be the right thing to do even with access.

What this **is**: a swept flying wing designed from scratch to the
configuration in the photo — swept tapered wing, upturned winglets, single
dorsal fin, pusher prop on a blended centre pod — with the aerodynamics
actually worked rather than eyeballed. Every dimension is a parameter in
`JW` at the top of `tools/jetwing.py`. Give me PlanePrint's real numbers and
they drop straight in.

## The part that makes a tailless wing different

There is no tailplane to balance the wing's nose-down pitching moment, so the
wing has to balance itself. Two mechanisms, and both are tuned here against
theory rather than guessed:

**Reflex** — the trailing edge curves up, which flips the section's own moment
from nose-down to nose-up. The reflex is solved by bisection against
thin-aerofoil theory to hit a target Cm:

```
A1 = (2/π) ∫ dz/dx · cos θ dθ        Cm(c/4) = (π/4)(A2 − A1)
A2 = (2/π) ∫ dz/dx · cos 2θ dθ       α_L0   = −(1/π) ∫ dz/dx (cos θ − 1) dθ
```

The implementation is checked against NACA 4412, where it returns
α_L0 = −4.15° against a published −4.1°.

**Washout** — the tips are twisted nose-down, and on a *swept* wing the tips
sit behind the CG, so they work as a tailplane. Trim is solved by strip
theory over 80 spanwise strips: the CG is found by bisecting for the point
where dCm/dCL = 0 (the neutral point), then set forward of it by the static
margin, and the trim angle found by bisecting for Cm = 0.

A finding from the sweep that surprised me: **camber barely moves the trim
point.** More camber needs more reflex to hold the same Cm0, and the two
cancel in α_L0. Washout and the Cm0 target are the real levers.

## Specification — larger wing

| | |
|---|---|
| Span | 1500 mm (1583 mm tip to tip over the winglets) |
| Length / height | 621 / 281 mm |
| Wing area | 3675 cm², AR 6.12, taper 0.44 |
| LE sweep | 24° |
| MAC | 257.3 mm at y = 327 mm |
| Section | 10.5 % thick, 2.2 % camber, reflex 0.0196 aft of 65 % chord |
| | → Cm(c/4) **+0.0060**, zero-lift angle +0.87° |
| Washout | −3.0° at the tip |
| Neutral point | 25.0 % MAC |
| **Centre of gravity** | **263 mm from the nose = 17.5 % MAC** |
| Static margin | 7.5 % |
| Trims at | 6.5° for C_L 0.366 |
| At 880 g | 23.9 g/dm², trim 10.2 m/s, stall 6.7 m/s |

The 1200 mm version is the same shape scaled: CG 211 mm from the nose, 493 g,
stall 6.3 m/s.

## Why 3° of washout and not less

A swept wing that stalls at the tip first pitches **nose-up**, because the
tips are behind the CG. On an aircraft with a tailplane that is recoverable.
On a tailless wing it is a departure — the stall deepens itself. Three degrees
is the usual insurance and it costs very little: the trim sweep shows it moves
trim C_L from 0.16 (no washout) to 0.37.

## Build notes

- **Set the CG before anything else.** 17.5 % MAC with a 7.5 % static margin is
  a sport setting. If it feels pitchy, move the battery forward; a tailless
  wing gives much less warning than a conventional one.
- Elevons are scribed at 28 % chord from 34 % to 96 % semi-span.
- The pod datum is set 5° nose-down against the root chord so the body looks
  level at the 6.5° trim attitude.
- The fin is sized by eye from the photo, not by a yaw-stability calculation —
  a flying wing's directional stability depends on winglet area as much as the
  fin, and I would want the real aircraft's numbers before claiming one.

## Changing anything

Everything is in the `JW` dict:

```python
"span": 1500.0, "root_chord": 340.0, "sweep_le": 24.0,
"washout_tip": -3.0, "target_cm": 0.006, "static_margin": 0.075,
```

Change a value and the geometry, trim solution, CG and spec sheet all follow.

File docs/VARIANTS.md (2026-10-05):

# Airframe variants

```bash
python3 tools/variants.py
```

Writes four 3D models to `models/variants/` as STL and OBJ, plus renders to
`docs/img/variants/`.

These are the aircraft **as the printed plans actually produce it**: no
retractable motor pylon, no retractable turbine mast, and therefore no dorsal
spine and no keel fairing either — those two exist only to swallow the
retracting pods, so with the pods gone they are pure drag and they go too.

| Variant | Span | Motor | Mass | Wing loading | Stall | L/D | Min sink |
|---|---|---|---|---|---|---|---|
| `glider-2000` | 2.00 m | none | 741 g | 20.7 g/dm² | 5.3 m/s | 16.7 | 0.36 m/s |
| `motor-2000` | 2.00 m | nose folder | 833 g | 23.3 g/dm² | 5.6 m/s | 16.6 | 0.39 m/s |
| `glider-2500` | 2.54 m | none | 1059 g | 18.9 g/dm² | 5.0 m/s | 16.7 | 0.35 m/s |
| `motor-2500` | 2.54 m | nose folder | 1151 g | 20.6 g/dm² | 5.3 m/s | 16.6 | 0.37 m/s |

Each model carries the full wing solar array, scribed hinge lines on the
ailerons, flaps and ruddervators, the ventral sensor turret, and the real
FF-SC1 section lofted through every station — everything in the FF-1 model
except the two retractable pods and their housings.

C_D0 is 0.0316 (0.0320 with the nose motor), built from the design component
table with the spine, keel fairing, bay doors and solar-cell steps removed and
a foam-surface penalty added. The composite FF-1 is 0.0247.

## The motor

Nose-mounted folding prop, which is available because the sensor turret is
slung **under** the nose rather than on it. No pylon, no bay, no actuator — the
blades simply fold back against the fuselage when the motor is off. This is
"Variant N" from [DESIGN.md](DESIGN.md) §10, which already came out lighter and
lower-drag than the retractable pylon.

## The larger version is scaled whole, not re-winged

`glider-2500` and `motor-2500` are the entire aircraft at ×1.25 — wing, tail,
fuselage, everything. That is deliberate.

Geometric scaling preserves the ratios that keep an aircraft trimmed and
stable. Tail volume coefficients and CG position come out **identical**:

| | V_h | V_v | CG |
|---|---|---|---|
| Both spans, scaled whole | 0.551 | 0.0306 | 34.2 % MAC |
| Span stretched to 2.5 m on the same fuselage and tail | 0.441 | 0.0196 | — |
| Target band | 0.45 – 0.70 | 0.020 – 0.035 | — |

Bolting a longer wing onto the existing fuselage drops **both** tail volumes
just below their bands — the fin loses a third of its authority. It would fly,
but it would wander in yaw and want a bigger tail to fix. Scaling everything
avoids the problem instead of trading against it.

One free bonus: the 2.5 m version has *lower* wing loading than the 2.0 m
(18.9 against 20.7 g/dm²), because the electronics and battery do not scale
with the airframe. It will thermal better.

## Mass scaling

Structure scales with the geometric factor, bought gear does not:

| Scaling | Applies to |
|---|---|
| k³ (volume) | wing cores, carbon spar |
| k² (area) | skins, pod, boom, tail, control surfaces |
| k⁰ (fixed) | motor, ESC, battery, RX, servos, flight controller |

## What is in each model

| Group | |
|---|---|
| `wing_stbd` / `wing_port` | FF-SC1 lofted through every station, with dihedral and washout |
| `solar_cells` | 34 cell strips, surface-conforming |
| `panel_lines` | scribed hinge lines, aileron / flap / ruddervator, both surfaces |
| `fuselage` | pod and boom |
| `sensor_turret` | ventral, under the nose |
| `vtail_stbd` / `vtail_port` | 38° dihedral |
| `nose_motor` | spinner and folding blades — motor variants only |

Deliberately absent: the retractable motor pylon, the energy-recovery turbine
mast, the dorsal spine and the keel fairing. The last two only existed to
swallow the first two.

## Changing the span

Edit `VARIANTS` in `tools/variants.py` — the scale factor is the second field:

```python
("glider-3000", 1.50, "none", "3.0 m glider"),
```

Everything downstream follows: geometry, mass, performance, stability.

## Files

```
models/variants/glider-2000.stl   .obj
models/variants/motor-2000.stl    .obj
models/variants/glider-2500.stl   .obj
models/variants/motor-2500.stl    .obj
docs/img/variants/*.png           renders, plus size-comparison.png
```

The OBJ files carry named groups (`wing_stbd`, `fuselage`, `vtail_port`,
`nose_motor`, `solar_cells`, `panel_lines`, …) so you can hide or re-colour parts in a CAD or 3D tool. The
STL is a visual/assembly model: components interpenetrate where they join, so
boolean them before slicing if you intend to print one.

Units are millimetres; +X aft with the nose at the origin, +Y starboard, +Z up.

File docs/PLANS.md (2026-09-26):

# Printable build plans

```bash
python3 tools/plans.py
```

Writes `plans/FF-1_plans_A4.pdf` — 22 A4 sheets at exact full size — plus
`plans/dxf/` outlines for anyone with a CNC hot-wire or laser cutter.

## Print settings, and why they matter

**100 % / "Actual size". Turn off "Fit to page", "Shrink oversized pages" and
"Scale to fit".**

Those options are on by default in most print dialogs and take 4–6 % off. On
this aircraft a 5 % shrink moves the centre of gravity 3 mm forward of where
the plan marks it and shortens every chord, so the wing you cut is not the
wing that was designed. Every sheet carries a 100 mm bar — measure it with a
steel rule before you cut anything.

The PDF's page box is exactly 595.276 × 841.890 pt (210 × 297 mm) and the
drawing transform is 2.834646 pt/mm, so 100 drawing units land at 100.00001 mm
on paper. Any error you measure is the printer, not the file.

## What it is, and what it is not

A **foam prototype of the FF-1's aerodynamic shape** — wing, V-tail and
fuselage pod at full size. This is phase 1 of the flight test plan in
[DESIGN.md](DESIGN.md) §11: the aircraft that gets you a measured sink polar
before you commit to composite moulds.

It is **not** the solar aircraft. The array, the energy-recovery turbine and
the retractable motor pylon all need the moulded airframe — foam has neither
the stiffness to carry a flat cell array without cracking cells nor the
internal volume for the mast trunk. The planform, section, tail volumes and CG
are identical, so what you learn transfers directly.

## Sheets

| Sheets | |
|---|---|
| 1 | Title, print check, key numbers, sheet index |
| 2 | Build notes — tiling, two ways to make the wing, build order, balance |
| 3–9 | Wing panel, full size. Cut 2, one mirrored |
| 10 | **How the wing is cut** — schematic, not to scale |
| 11–12 | Aerofoil templates, FF-SC1 at 195 / 160 / 128 / 92 mm chord |
| 13–18 | Fuselage pod, side and plan |
| 19–21 | Formers |
| 22–23 | V-tail panel. Cut 2, one mirrored |

## Tiling

Tiles overlap by 12 mm. Trim along the dashed line on the **overlapping** sheet
only, lay it over its neighbour, line up the solid triangles and tape. Corner
crosses coincide when it is right. Work along a row, then join rows. Each sheet
is labelled `R<row>C<column>`.

## Two ways to make the wing

**The planform sheets are not the cut outline for a solid wing.** A hot wire
spans two templates and sweeps a *ruled* surface between them, so the aerofoil
comes from the template sheets at the ends of the block. The planform is the
plan-view check and the marking guide for the spar and hinge lines. Sheet 10
shows the setup.

**Hot-wire cores** — accurate, needs a wire bow. Transfer the aerofoil sheets
to 1.5 mm ply or aluminium, pin one at each end of an XPS block, and run the
wire along both at once. Every template carries the same numbered index marks
at 5 / 10 / 20 / 30 / 45 / 60 / 75 / 90 % chord: call the numbers out loud and
move together. The root end travels further per number because its chord is
longer, and that is exactly what cuts the taper.

**Four cuts per side, not one.** The planform changes taper three times, and a
wire can only make straight lines between corresponding points:

| Segment | Length | Templates |
|---|---|---|
| y 0 – 450 | 450 mm | 195 and 195 (constant section) |
| y 450 – 850 | 400 mm | 195 and 160 |
| y 850 – 960 | 110 mm | 160 and 128 |
| y 960 – 1000 | 40 mm | 128 and 92 — hand-shape this one |

Trying to do it in one cut from the break to the tip would give 120 mm of
chord at y = 850 instead of 160 mm, losing about 40 mm of chord and a
meaningful slice of wing area per side.

Rotate the tip template 2° trailing-edge-up on the outboard panels for
washout, and align the 0 % marks of both templates on one straight line — the
leading edge is unswept.

**Flat foam** — quick, no tools. Cut the planform from 6 mm Depron, score the
underside along the spar line and fold a leading-edge wrap over the carbon
tube. Costs about 15 % of L/D against the true section; planform and CG are
unchanged.

## Materials

Quantities are for one aircraft, taken from the plan geometry.

### Foam — which type matters

| Part | Material | Quantity |
|---|---|---|
| Wing cores *(hot-wire route)* | **XPS** insulation board, 25 mm, 30–35 kg/m³ | 2 blocks 1000 × 205 × 24 mm — one 1250 × 600 board does both |
| Wing *(flat-foam route)* | **Depron / XPS sheet, 6 mm** | 0.36 m² planform + LE wrap → one 1250 × 800 sheet |
| Fuselage pod sides | Depron, 3 mm | 2 off, 620 × 96 mm |
| V-tail | Depron or XPS, 5 mm | 2 off, 300 × 140 mm |
| Formers | 3 mm liteply *(or 5 mm Depron)* | 8 off, largest 80 × 96 mm |

**XPS** — extruded polystyrene, the blue/pink/grey building insulation board.
Closed-cell, smooth, hot-wires cleanly, cheap. This is the one for cut cores.

**EPS** — the white beady packaging stuff. Cuts, but the bead texture wrecks
the surface finish and it is weaker for the same density. Not for the wing.

**EPP** — tough and bouncy, survives crashes. Too floppy and too heavy here;
it would blunt the section and spoil the polar measurement, which is the whole
point of this airframe.

### Everything else

| | |
|---|---|
| Main spar | 8 mm OD × 6 mm ID pultruded carbon tube, 2 × 1000 mm, plus a 6 mm joiner ~200 mm |
| Tail boom | 16 mm OD carbon tube, 660 mm (90 mm buried in the pod) |
| Wing skin | 25 g/m² glass cloth + laminating epoxy, **or** heat-shrink laminating film / fibre-reinforced packing tape |
| Adhesive | Epoxy, PVA/white glue, foam-safe CA, or hot glue |
| Hinges | Clear packing tape, or Blenderm surgical tape |

### The mistake that ruins foam builds

**Polystyrene dissolves in petrol-based solvents, polyester resin and ordinary
CA accelerator.** Standard cyanoacrylate and rattle-can paint will eat straight
through XPS and Depron. Use epoxy, PVA, *foam-safe* CA, or hot glue, and test
any paint on an offcut first.

### The skin is not optional

A bare foam wing has roughly twice the parasite drag of a skinned one — the
open cell texture trips the boundary layer everywhere. The C_D0 of 0.031 that
the performance prediction assumes is for a skinned, sanded surface. Skip the
skin and you will measure an L/D nearer 11 than 15.6, and you will wrongly
conclude the design is bad.

## Predicted performance

At the 833 g target mass in the plan's budget, with C_D0 taken as 0.031 for a
foam build (rougher surface, blunter leading edge, exposed linkages):

| | |
|---|---|
| Wing loading | 23.3 g/dm² — lighter than the composite aircraft |
| Stall | 5.6 m/s |
| Best glide | L/D 15.6 at 6.4 m/s |
| Minimum sink | 0.41 m/s |

It flies slower and thermals better than the FF-1 because it carries no array,
no turbine and no mast.

## Then measure it

Fit a flight controller and an **airspeed sensor**, fly the polar sortie in
[FLIGHT_ANALYSIS.md](FLIGHT_ANALYSIS.md) §4, and run:

```bash
python3 tools/flight_analysis.py YOURLOG.BIN --mass 0.83
```

That returns the measured sink polar and the drag level against this
prediction. Closing that loop — print, cut, fly, log, fit — is the entire
point of building the foam one first.

## Regenerating

Every dimension comes from `tools/config.py` through `tools/build_model.py`,
so the plans, the 3D model, the analysis and the mass budget cannot drift
apart. Change a chord there and re-run `python3 tools/plans.py`.

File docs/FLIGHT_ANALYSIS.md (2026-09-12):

# Flight log analysis

Feed it a log, get graphs and predictions.

```bash
python3 tools/flight_analysis.py data/example_flight.csv --open
python3 tools/flight_analysis.py 00000042.BIN --mass 1.68
```

Writes a self-contained HTML report to `reports/`. No dependencies — standard
library Python 3.8+, so it runs on the laptop at the flying field without a
`pip install`.

Try it now: `data/example_flight.csv` is a synthetic 2.6-hour flight generated
by `tools/simulate_flight.py` against the real design model, so you can see
the whole pipeline before the aircraft exists.

---

## 1. What it does

| Stage | |
|---|---|
| **Read** | ArduPilot `.BIN` straight off the SD card, ArduPilot `.log` text, or any CSV. Column names are matched fuzzily — whatever your log calls airspeed comes out as `airspeed` |
| **Derive** | climb rate (least-squares slope over a ±2 s window, so baro noise is averaged rather than differentiated), air density, electrical power, cumulative energy |
| **Segment** | powered / thermalling / turbine-deployed / gliding, median-filtered so one banked sample is not a thermal |
| **Fit** | the drag polar, from stabilised glide legs |
| **Predict** | drag level vs design, turbine harvest for that day's thermals, and endurance re-run on the measured drag |

---

## 2. How the polar fit works

Sink rate against airspeed, for a drag polar `C_D = A + D·C_L + B·C_L²`:

```
w(V) = (A/K)·V³ + D·V + (B·K)/V        K = 2W/(ρS)
```

Three terms, linear in the coefficients, so ordinary least squares recovers
them from a handful of stabilised glides. Everything downstream — L/D max,
best-glide speed, minimum sink — then follows from the curve.

Three things the tool does that matter:

**It reduces every leg to sea-level density.** At the same indicated airspeed
you fly faster and sink faster at altitude, both by √(ρ₀/ρ), so each leg's
sink is corrected before fitting. Otherwise a polar flown from 500 m down to
200 m has a built-in trend.

**It drops legs that were flown in lift.** A leg through weak rising air reads
as impossibly low sink and drags the whole fit with it. Points more than 2σ
*below* the curve are rejected and refitted (two passes); they appear as
hollow circles on the polar. Points above the curve are kept — sink and
turbulence are honest.

**It picks the fit order by cross-validation.** Two terms (the textbook
`aV³ + b/V`) forces `D = 0`, which biases both C_D0 and e — on synthetic data
with a known answer, by 12 % and 20 %. Three terms fits better but needs more
points. Leave-one-out CV decides, and the report prints both errors.

---

## 3. Read the confidence flags, not just the numbers

A sink curve determines **total** drag well. Splitting it into parasite and
induced drag is a different question, and often the data cannot answer it: over
a narrow speed range V³, V and 1/V are nearly collinear, so very different
coefficient pairs fit the same curve almost equally well.

So the report bootstraps — resamples the glide legs 300 times, refits, and
quotes 10–90 % intervals. On the example flight:

| | Fitted | Interval | Verdict |
|---|---|---|---|
| L/D max | 18.07 | 17.8 – 18.4 | usable, ±2 % |
| Speed for best glide | 10.04 m/s | 9.8 – 10.1 | usable, ±2 % |
| C_D0 | −0.048 | −0.088 – −0.022 | **not identifiable** — a negative C_D0 is impossible |

That is the tool working correctly. The curve is nailed; the decomposition is
not, and it says so rather than printing a confident wrong number.

**So the headline drag metric is a single scale factor:** the multiplier on
design C_D0 that reproduces the measured L/D. One parameter fitted to one
well-determined quantity, always identifiable, and it is what you actually
want to know — *is the aircraft draggier than predicted, and by how much?*
On the example it comes back ×0.95 [0.92–0.98], against a true value of ×1.00.

---

## 4. Fly a polar sortie properly

This is phase 1 of the flight test plan in [DESIGN.md](DESIGN.md) §11, and it
is the single most valuable data set in the programme.

- **Calm air.** Early morning or late evening. Thermals are the dominant error
  source and no amount of fitting fixes them.
- **Seven speeds or more**, from just above stall to about 2.5× stall — for the
  FF-1 that is roughly 8, 9, 10.5, 12, 14, 17, 20 m/s. A narrow range is what
  makes C_D0 unidentifiable.
- **Three repeats per speed**, non-consecutive, so a single gust does not
  become a data point.
- **30 s per leg**, wings level within ±5°, motor off, airspeed steady to
  ±0.3 m/s. The tool requires 20 s windows with bank under 6° and airspeed
  acceleration under 0.05 m/s²; anything looser is rejected.
- **Know the mass.** Pass `--mass` in kg. The polar scales with √(W/S) and the
  coefficients scale with W directly.
- **Log airspeed.** Groundspeed is a fallback and the report warns loudly when
  it has been used: a 3 m/s wind biases L/D by tens of percent depending on
  heading.

---

## 5. What to log

Channels the tool understands. Everything is optional except `alt`, and
`airspeed` for the polar.

| Channel | Unit | Why |
|---|---|---|
| `alt` | m | required; climb rate comes from it |
| `airspeed` | m/s | required for the polar |
| `roll` | deg | separates thermalling from gliding, rejects banked legs |
| `throttle` | 0–1 | separates powered flight from gliding |
| `volt`, `curr` | V, A | pack power and energy |
| `solar_w` | W | MPPT output — **FF-1 specific, add this message** |
| `turbine_w` | W | turbine controller output — **FF-1 specific** |
| `mast_mm` | mm | turbine mast extension — **FF-1 specific** |
| `temp` | °C | outside air temperature, improves the density correction |
| `groundspeed`, `pitch`, `used_mah`, `lat`, `lon` | | used where present |

`python3 tools/flightlog.py` with no arguments prints the full alias list.

The three FF-1-specific channels need a custom ArduPilot log message from the
power subsystem. They are worth the trouble: without them the energy
accounting is a single battery number, and the turbine's contribution — the
thing the whole §5.5 argument in [ANALYSIS.md](ANALYSIS.md) rests on — cannot
be measured at all.

---

## 6. Options

| | |
|---|---|
| `--mass KG` | flight mass; defaults to design MTOW |
| `--dt S` | resample interval, default 0.5 s |
| `--window S` | glide window length for polar legs, default 20 s |
| `-o PATH` | output file |
| `--open` | open the report in a browser when done |

## 7. Charts

Colours come from a categorical palette validated for colour-vision
deficiency, contrast and chroma in both light and dark mode. Fixed assignment,
never cycled: **orange = powered/motor, teal = turbine/regen, amber = solar,
purple = measured/glide**. Status green and red are reserved for the
confidence flags and never used as series colours.

The time-series charts have a crosshair and tooltip on hover. The report is
one self-contained file — no network needed except web fonts, which degrade to
system fonts offline.

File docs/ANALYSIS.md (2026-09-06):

# FF-1 *Ember* — computed analysis

> Generated by `tools/analysis.py` from `tools/config.py`. Do not hand-edit; re-run the script.

Wing loading **44.4 N/m² (4.53 kg/m²)**, MTOW **1622 g**, span **2.00 m**, area **0.3580 m²**, AR **11.17**.

## 1. Mass budget

| Group | Item | g | 1σ |
|---|---|---|---|
| Structure | Wing: spar caps, webs, D-box, ribs | 168 | ±18 |
| Structure | Wing: skins, ETFE, joiner tube | 142 | ±16 |
| Structure | Wing: control surfaces + hinges | 34 | ±5 |
| Structure | Fuselage pod (Kevlar/carbon) | 88 | ±10 |
| Structure | Tail boom (carbon, tapered) | 38 | ±4 |
| Structure | V-tail assembly | 46 | ±6 |
| Propulsion | Motor (outrunner, 480 Kv class) | 52 | ±4 |
| Propulsion | ESC (bidirectional, 30 A) | 19 | ±2 |
| Propulsion | Folding prop + spinner + hub | 27 | ±3 |
| Propulsion | Pylon, 4-bar, over-centre lock | 58 | ±8 |
| Propulsion | Pylon actuator + bay doors | 31 | ±5 |
| Recovery | Turbine rotor + hub | 18 | ±3 |
| Recovery | Generator (low-Kv, custom wound) | 44 | ±5 |
| Recovery | Regen controller (FOC) | 26 | ±3 |
| Recovery | Mast: fixed trunk + bulkhead doublers | 16 | ±3 |
| Recovery | Mast: 3 telescoping stages | 32 | ±5 |
| Recovery | Mast: pinions, bushings, racks | 10 | ±2 |
| Recovery | Micro linear actuator + mount | 46 | ±4 |
| Recovery | Bellcrank, con-rod, pivots | 9 | ±2 |
| Recovery | Bay doors, cam, wiper seal | 14 | ±3 |
| Recovery | End sensors, magnets, wiring | 9 | ±2 |
| Energy | Li-ion 3S1P 21700 (5.0 Ah cells) | 212 | ±6 |
| Energy | BMS, fuse, pack wiring, tray | 27 | ±4 |
| Energy | Solar cells (installed) | 104 | ±8 |
| Energy | Encapsulation, buses, bypass diodes | 42 | ±6 |
| Energy | 3-channel MPPT | 34 | ±4 |
| Avionics | Flight controller + IMU + baro | 21 | ±2 |
| Avionics | GNSS + compass | 11 | ±1 |
| Avionics | Control link RX + antenna | 12 | ±2 |
| Avionics | Servos (4 x 8 g wing/tail) | 32 | ±3 |
| Avionics | Airframe wiring, connectors | 28 | ±6 |
| Payload | LWIR radiometric core + lens | 14 | ±2 |
| Payload | Visible camera module | 9 | ±1 |
| Payload | Edge compute board + shield | 16 | ±2 |
| Payload | LoRa/telemetry radio + antenna | 17 | ±2 |
| Payload | Sensor turret shell + damping | 24 | ±4 |

**By group**

| Group | g | share |
|---|---|---|
| Structure | 516 | 33.7 % |
| Energy | 419 | 27.4 % |
| Recovery | 224 | 14.6 % |
| Propulsion | 187 | 12.2 % |
| Avionics | 104 | 6.8 % |
| Payload | 80 | 5.2 % |
| *Itemised total* | 1530 | 100.0 % |
| *Growth allowance (6 %)* | 92 |  |
| **MTOW** | **1622** |  |

Root-sum-square uncertainty on the itemised total is ±35 g. The build must be weighed bay by bay against this table; a 10 % overrun costs about 5 % in sink rate.

## 2. Aerodynamics
### 2.1 Zero-lift drag build-up

| Component | ΔC_D0 | share | basis |
|---|---|---|---|
| Wing profile (at design CL) | 0.01100 | 44.5 % | Re ~ 120,000, SD7037-class section |
| Fuselage pod + boom | 0.00205 | 8.3 % | S_wet 0.078 m2, Cf 0.0060, FF 1.35 |
| V-tail | 0.00200 | 8.1 % | S 0.0705 m2, Cd_p 0.0102 |
| Sensor turret | 0.00095 | 3.8 % | faired ball, 62 mm |
| Interference + gaps | 0.00190 | 7.7 % | hinge lines, wing root, antennas |
| Solar cell steps | 0.00120 | 4.9 % | cell edges, bus ribbons under ETFE |
| Dorsal motor-bay fairing | 0.00110 | 4.4 % | spine, x 370-800 |
| Ventral turbine fairing | 0.00075 | 3.0 % | keel blister, x 345-585 |
| Bay door seams | 0.00055 | 2.2 % | four doors, taped edges |
| *Sum* | 0.02150 |  |  |
| *Uncertainty margin (15 %)* | 0.00322 |  |  |
| **C_D0 (both pods stowed)** | **0.0247** |  |  |

### 2.2 Section

`FF-SC1`: **9.48 %** thick at 28.1 % chord, **2.76 %** camber at 44.8 % chord. Upper-surface curvature inside the 19–90 % solar band is limited to R ≥ 400 mm, giving a bending strain of 0.0206 % in a 165 µm cell — roughly a factor of 7 below the ~0.15 % fracture strain of cut monocrystalline silicon.

### 2.3 Speed polar (both pods stowed, ρ = 1.17 kg/m³)

| C_L | V (m/s) | C_D | L/D | sink (m/s) | Re (MAC) |
|---|---|---|---|---|---|
| 0.20 | 19.49 | 0.0287 | 7.0 | 2.799 | 236,126 |
| 0.30 | 15.91 | 0.0294 | 10.2 | 1.559 | 192,796 |
| 0.40 | 13.78 | 0.0309 | 12.9 | 1.065 | 166,966 |
| 0.50 | 12.32 | 0.0333 | 15.0 | 0.821 | 149,339 |
| 0.60 | 11.25 | 0.0365 | 16.4 | 0.685 | 136,327 |
| 0.70 | 10.42 | 0.0406 | 17.2 | 0.604 | 126,215 |
| 0.80 | 9.74 | 0.0455 | 17.6 | 0.554 | 118,063 |
| 0.90 | 9.19 | 0.0513 | 17.6 | 0.523 | 111,311 |
| 1.00 | 8.71 | 0.0579 | 17.3 | 0.504 | 105,599 |
| 1.10 | 8.31 | 0.0653 | 16.8 | 0.494 | 100,685 |
| 1.20 | 7.96 | 0.0736 | 16.3 | 0.488 | 96,398 |

**Key speeds**

| Condition | V (m/s) | note |
|---|---|---|
| Stall, clean | 7.79 | C_Lmax 1.25 |
| Stall, flaps down | 7.00 | C_Lmax 1.55 |
| Minimum sink (theoretical) | 7.79 | sink 0.487 m/s — lies on the stall, unusable |
| Minimum sink (practical, 1.15 V_s) | 8.96 | sink 0.514 m/s, L/D 17.5 — **the soaring speed** |
| Best glide | 9.51 | L/D 17.6, sink 0.540 m/s |
| Survey cruise | 9.51 | flown at best glide; the payload swath is set by altitude, not speed |

Reynolds number at the mean aerodynamic chord runs 94,450–181,760. That is squarely in the range where laminar separation bubbles decide the drag, which is why the section and the surface finish matter more than the planform.

### 2.4 What the pods cost when deployed

| Configuration | C_D0 | L/D | sink (m/s) | sink penalty | L/D penalty |
|---|---|---|---|---|---|
| both stowed | 0.0247 | 17.6 | 0.540 | +0.0 % | −0.0 % |
| motor deployed | 0.0272 | 16.7 | 0.558 | +3.3 % | −4.9 % |
| turbine deployed | 0.0280 | 16.5 | 0.560 | +3.7 % | −6.3 % |
| both deployed | 0.0305 | 15.8 | 0.576 | +6.7 % | −10.4 % |

This is the number that justifies retraction, and it is smaller than intuition suggests: at a 2 m span and this wing loading, induced drag dominates at soaring C_L, so a parasite-drag increment is diluted. Retraction is still clearly right for the turbine — it has to stow for landing regardless — but see §7 for the motor-installation trade.

## 3. Propulsion

Chain efficiency: prop 0.68 × motor 0.84 × ESC 0.95 = **0.543**.

| V (m/s) | C_L | P_aero (W) | P_electrical (W) | W/kg |
|---|---|---|---|---|
| 8.0 | 1.19 | 8.0 | 14.8 | 9.1 |
| 8.7 | 1.00 | 8.4 | 15.4 | 9.5 |
| 9.2 | 0.90 | 8.7 | 16.1 | 9.9 |
| 10.0 | 0.76 | 9.6 | 17.7 | 10.9 |
| 11.0 | 0.63 | 11.2 | 20.6 | 12.7 |
| 12.0 | 0.53 | 13.2 | 24.4 | 15.0 |
| 13.0 | 0.45 | 15.9 | 29.2 | 18.0 |
| 15.0 | 0.34 | 22.9 | 42.2 | 26.0 |

Climb at 2.5 m/s needs **89 W** electrical (8.3 A on a 3S pack) — the sizing case for the motor, ESC and cell discharge rating. Cells must be rated ≥ 10 A continuous; high-capacity/low-current 21700s are the wrong choice here.

## 4. The turbine — what a dynamo can and cannot do

A turbine takes its electrical power out of the airstream. Extracting P watts electrically costs P/(η_gen·η_rect) watts of shaft power, and that shaft power is drag. **It cannot extend endurance in steady flight.** The numbers:

| V (m/s) | P in disc (W) | P shaft (W) | P electrical (W) | extraction drag (N) | rotor rpm |
|---|---|---|---|---|---|
| 10 | 10.3 | 3.7 | **2.4** | 0.37 | 3,183 |
| 12 | 17.9 | 6.4 | **4.2** | 0.54 | 3,820 |
| 15 | 34.9 | 12.6 | **8.1** | 0.84 | 4,775 |
| 18 | 60.3 | 21.7 | **14.1** | 1.21 | 5,730 |
| 20 | 82.7 | 29.8 | **19.3** | 1.49 | 6,366 |
| 25 | 161.5 | 58.2 | **37.7** | 2.33 | 7,958 |
| 30 | 279.1 | 100.5 | **65.1** | 3.35 | 9,549 |

Rotor Ø 150 mm, 4 folding blades, C_p 0.36 at λ = 2.5. Power scales as V³, so the turbine is nearly useless at soaring speed and genuinely useful in a descent.

### 4.1 Holding altitude while extracting - and why not to

| V (m/s) | P electrical (W) | sink without turbine (m/s) | lift needed to hold height (m/s) |
|---|---|---|---|
| 12 | 4.2 | 0.85 | **1.26** |
| 14 | 6.6 | 1.23 | **1.87** |
| 16 | 9.9 | 1.76 | **2.72** |
| 18 | 14.1 | 2.47 | **3.83** |
| 20 | 19.3 | 3.37 | **5.24** |
| 22 | 25.7 | 4.49 | **6.98** |

Read alone this table looks discouraging: to take 19 W while holding height you need a 5.6 m/s core, which is rare. **The resolution is that the aircraft should not hold height.** It cycles - climbs slowly and efficiently with the turbine stowed, then descends with it deployed - and cycling beats holding by a wide margin, because the climb happens at minimum sink instead of at 20 m/s. Section 5.5 works the cycle properly; that is the number to use, not this one.

### 4.2 A single regenerative descent

| V (m/s) | potential energy (Wh) | recovered (Wh) | recovery | sink (m/s) | descent time (s) |
|---|---|---|---|---|---|
| 12 | 2.21 | **0.46** | 21 % | 1.26 | 398 |
| 15 | 2.21 | **0.50** | 23 % | 2.26 | 221 |
| 20 | 2.21 | **0.51** | 23 % | 5.24 | 95 |
| 25 | 2.21 | **0.51** | 23 % | 10.26 | 49 |

One 500 m descent banks **0.51 Wh**, about 4 minutes of hotel load, and recovers 23 % of the potential energy almost regardless of descent speed - rotor power and airframe drag both scale as V-cubed, so the split between them barely moves.

**Per descent is the wrong unit.** What matters is the rate over repeated climb-and-descend cycles, and that is section 5.5. The flat recovery fraction is also why the optimum descent speed is around 14 m/s rather than 25: going faster does not recover a larger share, it just burns the altitude band sooner and spends more of the surplus on airframe drag.

Either way the turbine doubles as the airbrake, so the wing needs no spoilers and the approach can be flown steep and slow.

### 4.3 Mode C — emergency power

At 15 m/s the turbine makes **8.1 W**, against a hotel load of 7.9 W. With a dead pack and a dead array it will hold the autopilot, GNSS and telemetry link alive the whole way down. From 900 m at the resulting sink rate that is roughly 7 minutes of controlled, communicating flight. This is the same argument that puts a RAT in an airliner, and on its own it justifies carrying the turbine.

## 5. Energy
### 5.1 Array

|  |  | note |
|---|---|---|
| Wing strips | 34 | 11.33 full cells |
| Active cell area | 1771 cm² | 0.1771 m² |
| Nameplate at STC | 39.8 W | 1000 W/m², 25 °C |
| Installed chain efficiency | 15.5 % | cell × encapsulation × temperature × mismatch × MPPT × attitude |
| Output at 1000 W/m² horizontal | 27.5 W |  |
| Optional V-tail sub-array | +7.0 W STC | 6 strips — growth item, excluded from the budget below |

### 5.2 Clear-sky array output

**S. Europe / California, mid-Aug** — latitude 38.0°, day 227, clearness 0.78

| solar time | sun elevation (°) | GHI (W/m²) | array (W) |
|---|---|---|---|
| 06:00 | 8.4 | 93 | 2.6 |
| 07:00 | 20.2 | 319 | 8.8 |
| 08:00 | 32.0 | 556 | 15.3 |
| 09:00 | 43.5 | 768 | 21.1 |
| 10:00 | 54.0 | 935 | 25.7 |
| 11:00 | 62.4 | 1040 | 28.6 |
| 12:00 | 65.8 | 1077 | 29.6 |
| 13:00 | 62.4 | 1040 | 28.6 |
| 14:00 | 54.0 | 935 | 25.7 |
| 15:00 | 43.5 | 768 | 21.1 |
| 16:00 | 32.0 | 556 | 15.3 |
| 17:00 | 20.2 | 319 | 8.8 |
| 18:00 | 8.4 | 93 | 2.6 |
| 19:00 | -2.9 | 0 | 0.0 |
| 20:00 | -13.6 | 0 | 0.0 |

**UK / N. Europe, late June** — latitude 51.5°, day 172, clearness 0.68

| solar time | sun elevation (°) | GHI (W/m²) | array (W) |
|---|---|---|---|
| 06:00 | 18.1 | 206 | 5.6 |
| 07:00 | 27.3 | 368 | 10.1 |
| 08:00 | 36.7 | 532 | 14.6 |
| 09:00 | 45.7 | 678 | 18.6 |
| 10:00 | 53.7 | 793 | 21.8 |
| 11:00 | 59.7 | 867 | 23.8 |
| 12:00 | 61.9 | 892 | 24.5 |
| 13:00 | 59.7 | 867 | 23.8 |
| 14:00 | 53.7 | 793 | 21.8 |
| 15:00 | 45.7 | 678 | 18.6 |
| 16:00 | 36.7 | 532 | 14.6 |
| 17:00 | 27.3 | 368 | 10.1 |
| 18:00 | 18.1 | 206 | 5.6 |
| 19:00 | 9.4 | 70 | 1.9 |
| 20:00 | 1.5 | 0 | 0.0 |

### 5.3 Loads

| Load | W |
|---|---|
| Flight controller + IMU + baro | 1.10 |
| GNSS + compass | 0.35 |
| Control link RX | 0.30 |
| Servos (soaring duty) | 1.60 |
| LWIR core | 0.65 |
| Visible camera | 0.60 |
| Edge compute (50% duty) | 2.40 |
| Telemetry radio (avg) | 0.35 |
| MPPT + BMS quiescent | 0.45 |
| Deployment actuators (avg) | 0.10 |
| **Hotel total** | **7.90** |

Powered level cruise costs **16.7 W** electrical, so the hotel load is 32 % of the powered demand. On this aircraft a watt saved in avionics is worth more than a drag count.

Pack: 3S1P 21700, **52.8 Wh** nameplate, 44.9 Wh at 85 % DoD, **38.9 Wh** usable after a 6 Wh approach reserve.

### 5.4 Mission simulation

30 s steps from a 09:00 launch. There is no soaring "duty cycle" parameter. At each step the atmosphere offers `f x (w - s_circle)` of specific climb; if that beats what the airframe needs to stay up, the motor stays off and the **surplus is what the turbine takes**. If it does not, the motor makes up the shortfall and the turbine stays stowed. The soaring fraction below is an output, not an input.

| Site | Case | Endurance | Solar (Wh) | Turbine (Wh) | Motor (Wh) | Soaring | >= 8 h |
|---|---|---|---|---|---|---|---|
| S. Europe / California, mid-Aug | solar + soaring + turbine | **10.1 h** | 197 | 14.4 | 57 | 56 % | yes |
| S. Europe / California, mid-Aug | solar + soaring, turbine off | **10.1 h** | 197 | 0.0 | 57 | 56 % | yes |
| S. Europe / California, mid-Aug | solar only, no thermals | **9.1 h** | 196 | 0.0 | 145 | 0 % | yes |
| S. Europe / California, mid-Aug | thermals only, array failed | **1.5 h** | 0 | 0.0 | 23 | 0 % | - |
| S. Europe / California, mid-Aug | battery only | **1.5 h** | 0 | 0.0 | 23 | 0 % | - |
| UK / N. Europe, late June | solar + soaring + turbine | **10.0 h** | 176 | 2.8 | 84 | 32 % | yes |
| UK / N. Europe, late June | solar + soaring, turbine off | **10.0 h** | 176 | 0.0 | 84 | 32 % | yes |
| UK / N. Europe, late June | solar only, no thermals | **8.6 h** | 170 | 0.0 | 137 | 0 % | yes |
| UK / N. Europe, late June | thermals only, array failed | **1.5 h** | 0 | 0.0 | 23 | 0 % | - |
| UK / N. Europe, late June | battery only | **1.5 h** | 0 | 0.0 | 23 | 0 % | - |

**The 8-hour requirement is met by solar plus soaring, and is not met on batteries alone.**

### 5.5 What the turbine is actually worth

The turbine's operating case is the soaring cycle, not level flight. The aircraft climbs on atmospheric energy and descends on the turbine, so the source is the air and the output is **genuinely net positive**. The steady-flight objection only ever applied to steady flight, where there is no free energy coming in.

Sustainable electrical harvest, by the kind of day (W):

| Thermal strength (m/s) | in lift 25 % | in lift 30 % | in lift 35 % | in lift 40 % | in lift 45 % |
|---|---|---|---|---|---|
| 1.5 | - | - | - | - | **0.5** |
| 2.0 | - | **0.0** | **1.0** | **1.4**\* | **1.8**\* |
| 2.5 | **0.4** | **1.3** | **1.8** | **2.3** | **2.7** |
| 3.0 | **1.4**\* | **2.1** | **2.5**\* | **3.1** | **3.6** |
| 3.5 | **2.1** | **2.7** | **3.2**\* | **3.9** | **4.5**\* |
| 4.0 | **2.6**\* | **3.3**\* | **4.0** | **4.6**\* | **5.2** |

`-` = cannot soar unaided, the motor is running. `*` = rotor-limited: the atmosphere is offering more surplus than a 150 mm rotor can absorb at the optimum descent speed.

On a good day that is **3.6 W continuous** against a 7.9 W hotel load - about 46 % of the avionics and payload budget, taken from the air. Over a flight it comes to **14 Wh**, a quarter of the pack's nameplate capacity.

The optimum descent speed is **14 m/s**, not the 20-25 m/s a naive reading of the turbine's power curve suggests. Rotor power goes as V-cubed, but so does airframe drag, and past about 15 m/s the airframe eats the surplus faster than the rotor can take it.

#### The catch: on a good day there is nowhere to put it

| Array output | Condition | Turbine off | Turbine on | Gain | Harvest spilled |
|---|---|---|---|---|---|
| 100 % | clear sky, clean array | 10.07 h | 10.07 h | **+0.00 h** | 100 % |
| 75 % | haze or a soiled array | 9.98 h | 9.98 h | **+0.00 h** | 97 % |
| 55 % | thin overcast | 9.88 h | 9.90 h | **+0.02 h** | 74 % |
| 40 % | one of three strings failed | 9.10 h | 9.71 h | **+0.61 h** | 0 % |
| 30 % | heavy overcast | 7.98 h | 8.86 h | **+0.87 h** | 0 % |
| 20 % | array badly degraded | 2.56 h | 7.18 h | **+4.62 h** | 0 % |

**On a clear day every watt-hour the turbine makes is thrown away, because the array has already filled the pack.** The energy is real; the tank is full. The turbine pays exactly when the array cannot - overcast, soiling, a failed string, low winter sun - and in that band it is worth hours, not minutes.

That is a better reason to carry it than a daily contribution would be: it is the argument for any redundant system. It also means the deploy rule in section 6.1 is already right - **only harvest when the pack has room**. On a full pack the surplus should go into altitude or airspeed, banked as potential energy or spent on survey coverage, not into a turbine with nowhere to send it.

## 6. Stability and control

|  |  | note |
|---|---|---|
| Wing lift-curve slope a_w | 5.221 /rad |  |
| Tail lift-curve slope a_t | 4.378 /rad | projected AR 5.11 |
| Tail arm | 819 mm | wing a.c. to tail a.c. |
| Horizontal tail volume V_h | 0.551 | target 0.45–0.70 |
| Vertical tail volume V_v | 0.0306 | target 0.020–0.035 |
| Downwash dε/dα | 0.297 |  |
| Neutral point | 54.2 % MAC |  |
| **CG, target** | **34.2 % MAC** | 277 mm aft of the nose |
| CG, forward limit | 26.2 % MAC | 28 % static margin |
| CG, aft limit | 42.2 % MAC | 12 % static margin |

Deploying the pods moves the CG: the pylon rises and moves the motor mass up and aft, the turbine swings down and aft. Both are aft of the CG, so both deployments are slightly nose-up in pitch trim and both are stabilising in yaw. Trim the autopilot for the stowed case and let the pitch loop absorb the rest; the deployment transient is the thing to watch on the first flights, not the trimmed state.

## 7. Structure

|  |  | note |
|---|---|---|
| Limit load factor | 5.0 g | ultimate = 1.5 × limit |
| Root bending moment | 16.9 N·m | elliptic distribution |
| Root shear | 39.8 N |  |
| Spar cap | 9 mm × 3 plies UD | 3.10 mm² per cap at the root |
| Cap centroid separation | 15.9 mm | at the root rib |
| Root cap stress at limit | 343 MPa | vs ~700 MPa allowable for T700 UD |
| Margin of safety, ultimate | +0.36 |  |
| Root EI | 51 N·m² |  |
| Tip deflection at 1 g | 18 mm | 1.8 % of semi-span |
| Tip deflection at limit | 91 mm | 9.1 % of semi-span |

The wing is stiffness-driven, not strength-driven: the cap laminate is set by wanting a flat array (a flexing wing de-focuses nothing, but it does crack cells and open encapsulation seams) long before it is set by stress.

## 8. Trade study — motor installation

| Option | MTOW (g) | C_D0 stowed | L/D | sink (m/s) | ΔC_D0 when running |
|---|---|---|---|---|---|
| Deployable dorsal pylon (baseline, as requested) | 1622 | 0.0247 | 17.6 | 0.540 | 0.00250 |
| Nose folding prop (Variant N) | 1551 | 0.0231 | 18.2 | 0.516 | 0.00030 |

Variant N is **71 g lighter**, has **4.5 % less sink** and no mechanism to jam, because it deletes the pylon, its actuator, its doors and the dorsal spine that swallows it. The dorsal pylon buys three things in exchange: the prop disc is clear of the ground on a belly landing, the nose stays free for a forward-looking sensor if the ventral turret is ever outgrown, and thrust acts above the drag line so power changes do not pitch the aircraft as hard.

The baseline keeps the pylon because it is what was asked for and the penalty is real but small. If endurance is the only thing that matters, build Variant N.

## 9. Wildfire detection performance

|  |  |
|---|---|
| Survey altitude | 400 m AGL |
| Ground swath | 434 m |
| Ground sample distance | 2.71 m/pixel |
| Pixel ground footprint | 7.4 m² |
| Raw coverage | 14.9 km²/h at 9.5 m/s |
| Coverage with 30 % sidelap | **10.4 km²/h** |
| Over an 8 h sortie | **83 km²** |

Sub-pixel detection: the 8–14 µm band captures 38 % of a 27 °C background's emission but only 17 % of an 800 K flame's — LWIR is the *unfavourable* band for hot small fires, and these figures already account for that.

| Flame area (m²) | pixel fill | apparent pixel T (°C) | ΔT vs background | ΔT / NETD |
|---|---|---|---|---|
| 0.05 | 0.7 % | 36.1 | +9.1 | 182× |
| 0.10 | 1.4 % | 44.5 | +17.5 | 350× |
| 0.50 | 6.8 % | 98.3 | +71.3 | 1,425× |
| 1.00 | 13.6 % | 148.9 | +121.9 | 2,437× |
| 4.00 | 54.3 % | 353.3 | +326.3 | 6,527× |

**The sensor is not the limit — clutter is.** Sun-baked bare rock, dark soil and asphalt reach 55–70 °C on a summer afternoon, i.e. ΔT of +28 to +43 K. Anything below that threshold is indistinguishable from hot ground on a single frame, which puts the single-frame detection floor at roughly **0.5–1 m² of active flame**, not the 0.05 m² the raw NETD implies. Getting below that needs the contextual approach used by MODIS/VIIRS: compare each candidate pixel against the statistics of its own neighbourhood, require persistence across frames as the aircraft moves, and cross-check the visible camera for a smoke plume.

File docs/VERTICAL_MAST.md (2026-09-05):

# VDM-1 — vertical deployment mast

> Generated by `tools/mast.py`. Re-run after any change to `tools/config.py`.

A telescoping vertical mast that lowers the energy-recovery turbine **128 mm** straight down, driven by one micro linear actuator moving **42.7 mm**. It replaces the baseline swing arm (see [DESIGN.md](DESIGN.md) §6).

## 1. Why bother — the swing arm's real problem

A pivoting arm carries the turbine's mass through an arc. On the FF-1 the pod travels 157 mm aft between stowed and deployed, and that moves the centre of gravity **+12.9 mm — +7.1 % of mean chord**. Static margin falls from 20 % to 13 % the moment the turbine deploys, which is at the aft CG limit.

A mast that only moves vertically shifts the CG by **nothing**. Two other things come free with it:

- **The rotor axis stays aligned with the flow through the whole travel.** A swing arm at mid-stroke has the rotor at 45° to the airstream, which is a large asymmetric blade load exactly when the mechanism is least supported. That is what limits the speed at which you can move a swing arm.
- **Deployment depth becomes a continuous variable.** The mast can be part-extended, so the turbine's exposure — and therefore the drag it costs — can be modulated instead of being on or off.

What it costs is mass and parts: **+90 g**, taking sink rate from 0.524 to 0.542 m/s (+3.4 %). Endurance still closes above eight hours.

## 2. The stroke is set by the rotor, and nothing else

|  |  |
|---|---|
| Rotor radius | 75 mm |
| Disc clearance from the body | 30 mm (0.20 × rotor Ø) |
| Stowed package radius | 23 mm (nacelle + blades folded aft over it) |
| **Required stroke** | **128 mm** |

That sum is the whole sizing problem, and it does not care about stage count, station or fuselage depth — move any of those and the stroke stays at 128 mm. The only lever is the rotor, and shrinking it is not available: turbine power goes as R², so dropping to a 110 mm rotor costs 46 % of the output and takes Mode C (emergency power) below the hotel load, which is the mode that justifies carrying the turbine at all.

Clearance is the one soft number. 0.20 × diameter keeps the disc out of the fuselage boundary layer (about 12 mm at this station) and out of the worst of the flow curvature under the belly. Tightening it to 0.12 would save 12 mm of stroke at the cost of a non-uniform inflow across the disc — 1-per-rev blade loading, lost C_p, and noise.

## 3. Why it has to telescope

The fuselage is **73 mm deep** at station x = 425 mm (deck 38.5, keel -34.5). A single sliding mast needs its own length plus the stroke: retracted, its top ends up about 128 mm above where its deployed top was, so it would stand roughly 125 mm proud of the deck. There is nowhere to put that.

**Telescoping is not a refinement here — it is the only way 128 mm of travel fits inside 73 mm of airframe.** Stage count then trades three ways: more stages nest shorter and need less actuator stroke, but multiply the input force and add joint lash.

| Stages | Travel per stage (mm) | Nested height (mm) | Ventral fairing (mm) | vs 73 mm available |
|---|---|---|---|---|
| 1 | 128.0 | 204.0 | 169.0 | **131 mm too tall** |
| 2 | 64.0 | 104.0 | 69.0 | **31 mm too tall** |
| 3 | 42.7 | 70.7 | 35.7 | fits |
| 4 | 32.0 | 54.0 | 19.0 | fits |
| 5 | 25.6 | 44.0 | 9.0 | fits |

**Three stages.** Two will not nest; four fits but drives the actuator force past what a micro actuator delivers.

## 4. Mast

|  |  |
|---|---|
| Station | x = 425 mm, on the wing trailing-edge bulkhead |
| Sections (fore-aft × lateral) | 34.0×22.0 → 30.4×18.4 → 26.8×14.8 → 23.2×11.2 mm |
| Wall | 0.8 mm carbon |
| Stage length | 66.7 mm |
| Retained overlap | 24.0 mm at full extension |
| Nested height | 70.7 mm (fits under the deck) |
| Nacelle travel | z -47.2 → -175.2 mm |
| Deployed rotor disc | z -100 to -250 mm (216 mm below the keel) |
| Ventral fairing | 35.7 mm deep |

**The sections are rectangular, deep fore-aft.** Three reasons, and the first is the one that decides it:

1. The air load is fore-aft, so that is the axis that needs the second moment. Round tubes of the same mass put the mast's first bending mode on top of the rotor's 1-per-rev — see §6.
2. A non-circular section reacts the generator's torque without a keyway or a splined joint.
3. The flat faces are where the racks go.

## 5. Drive

```
micro linear actuator  (horizontal, along the fuselage)
        |
        |  1:1 bellcrank, 90 deg offset, equal arms
        v
stage 1 head  (Scotch-yoke slot -> pure vertical translation)
        |
        |  rack - pinion - rack doubler
        v
stage 2   (2 x stage 1)
        |
        |  rack - pinion - rack doubler
        v
stage 3   (3 x stage 1)  ->  nacelle, generator, rotor
```

A pinion carried on stage 1 meshes with a rack fixed to the trunk and a rack on stage 2, so stage 2 moves twice stage 1. A second pinion on stage 2 meshes with racks on stages 1 and 3, giving 3×. Module 0.4, Ø8 mm pinions.

Rack and pinion rather than cable reeving on purpose: it drives **positively in both directions** with one element per joint, there is nothing to tension or re-tension, and there are no dead centres. A reeved telescope needs a separate extend and retract cable per stage — four cables and four sheaves here — and every one of them is a creep-and-stretch item.

An equal-armed bellcrank with its arms 90° apart gives exactly 1:1 between the actuator's horizontal travel and the yoke's vertical travel, for any sweep angle. Arms 30 mm, pivot at x = 447 mm.

### 5.1 Loads

|  |  | basis |
|---|---|---|
| Air load at 20 m/s, rotor braked | 1.34 N | rotor 0.95 + mast 0.33 + nacelle 0.07 |
| Worst bushing couple | 8 N | moment / overlap at the lowest joint |
| Joint friction, all stages | 3.94 N | μ = 0.12, PTFE-lined on hard-anodised |
| Moving mass | 109 g | rotor, generator, nacelle, stages 1–3 |
| Weight at 3 g | 3.20 N | retract during a manoeuvre |
| **Design load at the mast** | **10.7 N** | ×1.5 for stiction and contamination |
| **At the actuator** | **41.1 N** | ×3 stages / 0.78 chain efficiency |

### 5.2 Actuator selection

Class figures for common micro linear actuators. **Verify against the current datasheet before ordering** — these are the numbers to size against, not a price list.

| Actuator class | Stroke (mm) | Force (N) | Mass (g) | Body (mm) | Deploy (s) | Margin |  |
|---|---|---|---|---|---|---|---|
| PQ12-P 100:1 | 20 | 50 | 15 | 44 | 7.1 | 1.2× | stroke short |
| L12-30 100:1 | 30 | 45 | 34 | 81 | 3.3 | 1.1× | stroke short |
| L12-30 210:1 | 30 | 80 | 34 | 81 | 7.1 | 1.9× | stroke short |
| L12-50 100:1 | 50 | 45 | 40 | 101 | 3.3 | 1.1× | thin margin |
| L12-50 210:1 | 50 | 80 | 40 | 101 | 7.1 | 1.9× | thin margin |
| L12-100 210:1 | 100 | 80 | 56 | 151 | 7.1 | 1.9× | thin margin |
| L16-50 63:1 | 50 | 150 | 84 | 128 | 3.3 | 3.7× | too heavy |

**L12-50 at 210:1.** 41 N needed against 80 N available — and the design load already carries a 1.5× stiction factor, so the margin on the physical load is nearer 3×. Deployment takes about 7 s, which is fine: nothing about deploying this turbine is time-critical, including Mode C.

If the build comes in heavy or the bushings measure worse than μ = 0.12, the fix is a **1.4:1 bellcrank with an L12-100**: the actuator then moves 60 mm for the same 42.7 mm at the yoke and the force requirement drops to about 29 N — 2.7× margin, for 16 g.

> **The actuator's lead screw is the only thing holding the mast in flight.** It must be a self-locking ratio (100:1 or 210:1, not 50:1), and that has to be verified on the bench with power removed and the full air load applied to the extended mast — not taken from the datasheet.

## 6. Structure and resonance

|  |  |
|---|---|
| First bending mode | 496 Hz |
| Rotor 1-per-rev at the top of the band | 133 Hz (7958 rpm at 25 m/s) |
| **Frequency ratio** | **3.7×** (want > 1.5) |
| Tip deflection, elastic | 0.00 mm under the air load |
| Tip deflection, joint lash | 0.94 mm at 0.04 mm per side |

This is the trap in the whole design. An unbalanced rotor is a rotating force at 1P, and a cantilevered mast carrying it is a tuning fork. Round tubes of comparable mass put the first mode within a few hertz of 1P — dead on resonance across the normal operating band. The rectangular sections move it clear by a factor of 3.7.

Back it up in the controller anyway. The generator's field-oriented controller sets the electrical load and therefore the rotor speed, so an **RPM avoid-band costs nothing** — exclude ±8 % around any measured resonance and let the controller step over it. Measure the real frequency with a ping test on the assembled, extended mast before the first spin-up; do not trust the calculation.
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

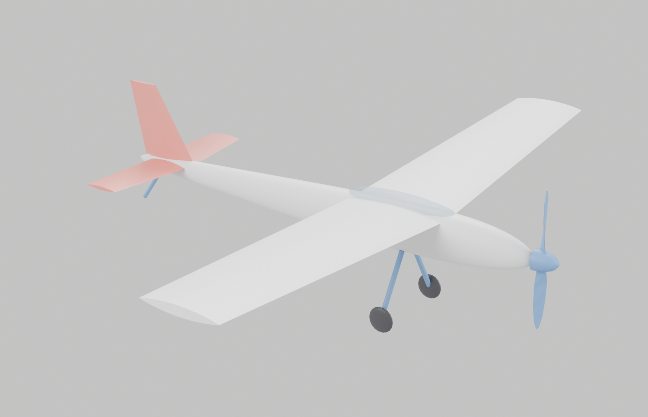
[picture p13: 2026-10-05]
docs/img/blender/plane-iso.png

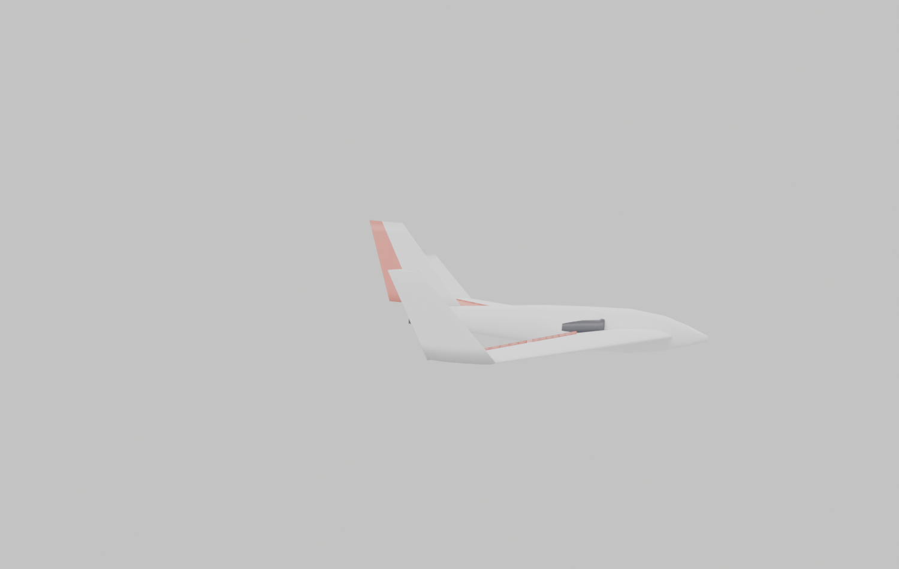
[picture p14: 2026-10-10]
docs/img/blender/jetwing-side.png

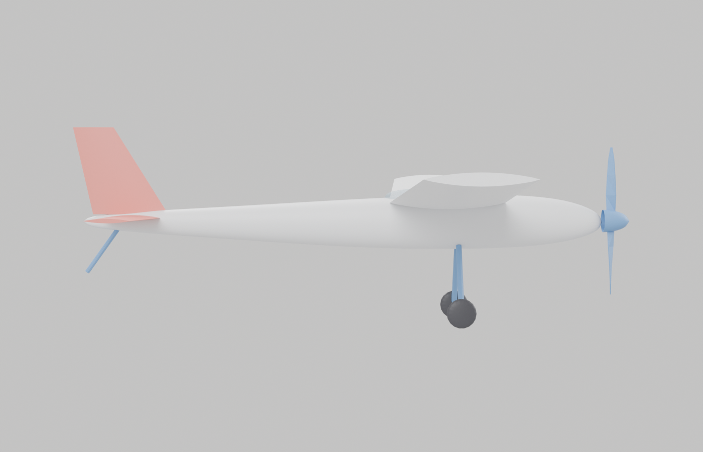
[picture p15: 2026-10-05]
docs/img/blender/plane-side.png

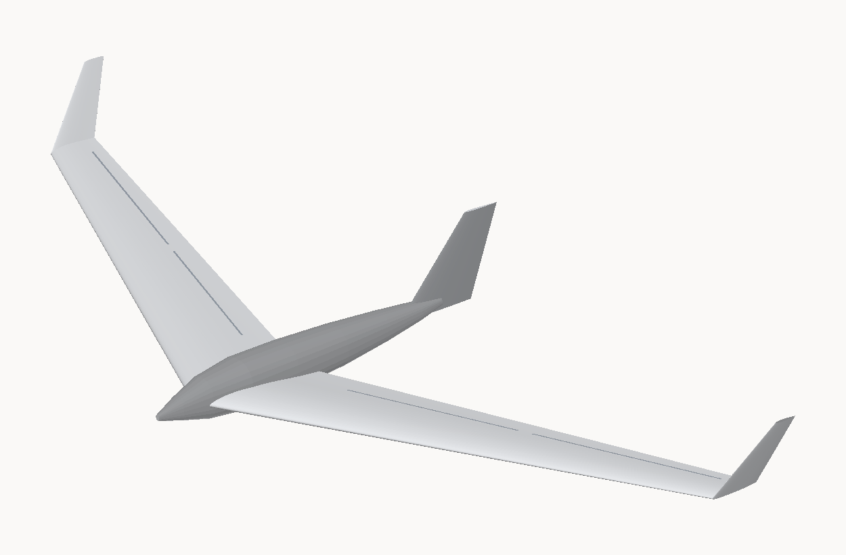
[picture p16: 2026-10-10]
docs/img/jetwing/jetwing-1200.png

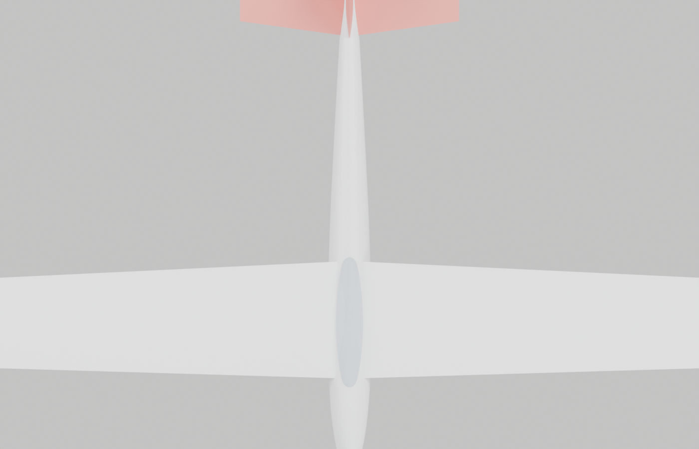
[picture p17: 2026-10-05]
docs/img/blender/plane-plan.png

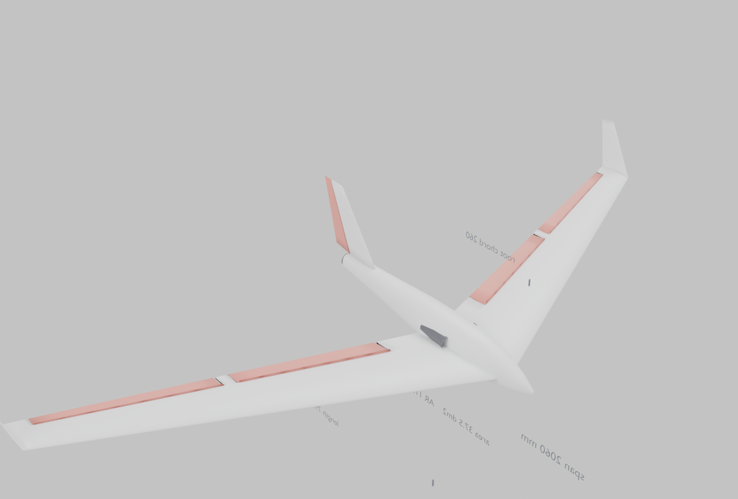
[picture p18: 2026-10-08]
docs/img/blender/jetwing-dims-iso.png

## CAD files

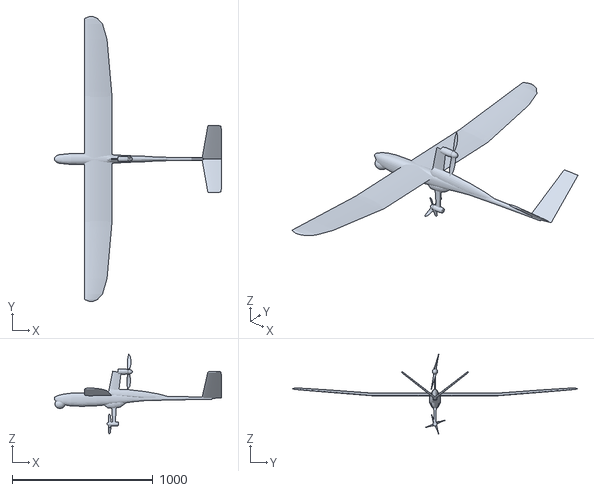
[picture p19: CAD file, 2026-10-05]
models/ff1_deployed.stl
1190.0 x 2028.0 x 567.0

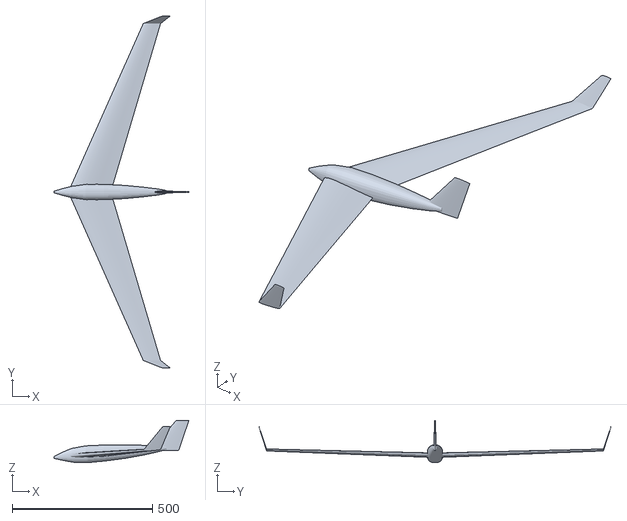
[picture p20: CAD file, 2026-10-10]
models/jetwing/jetwing-1200.stl
480.7 x 1254.0 x 150.9

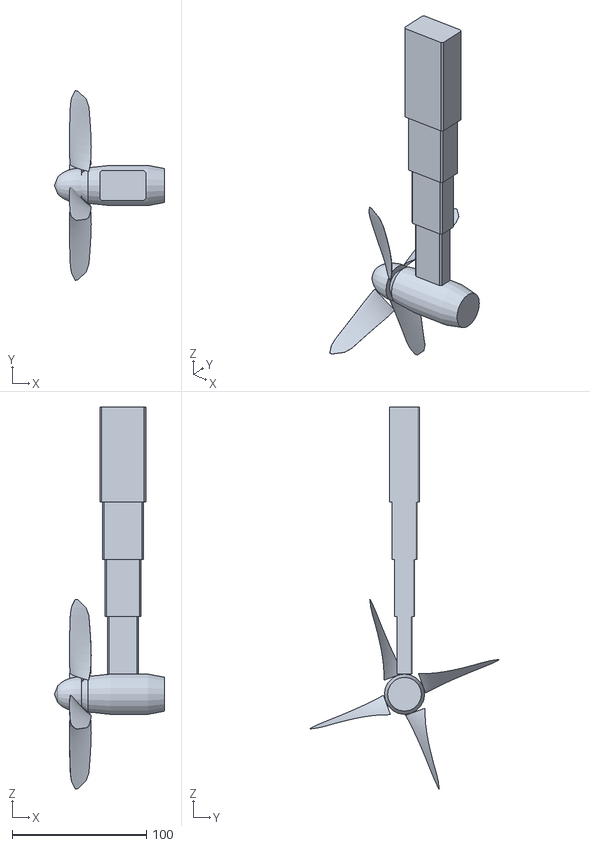
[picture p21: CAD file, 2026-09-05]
models/parts/rat_pod_deployed.stl
82.0 x 141.0 x 284.2

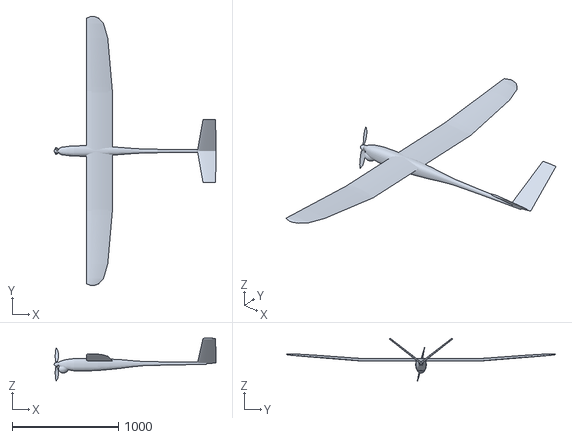
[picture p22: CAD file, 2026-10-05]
models/variants/motor-2500.stl
1525.0 x 2535.0 x 403.1

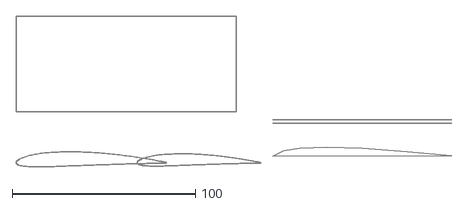
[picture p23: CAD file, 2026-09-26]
plans/dxf/howtocut.dxf
237.5 x 82.2

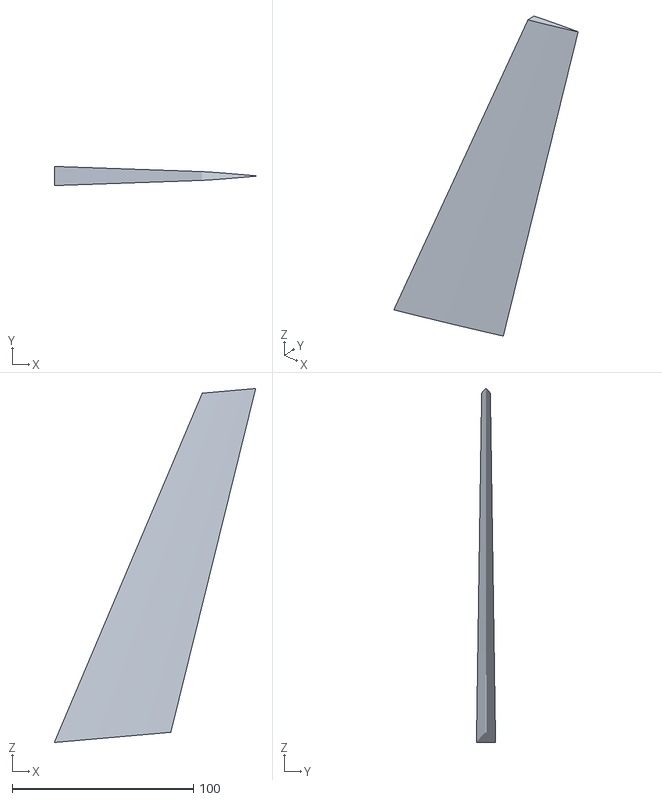
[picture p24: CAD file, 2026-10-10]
print/part_Rudder.stl
111.2 x 10.6 x 195.4

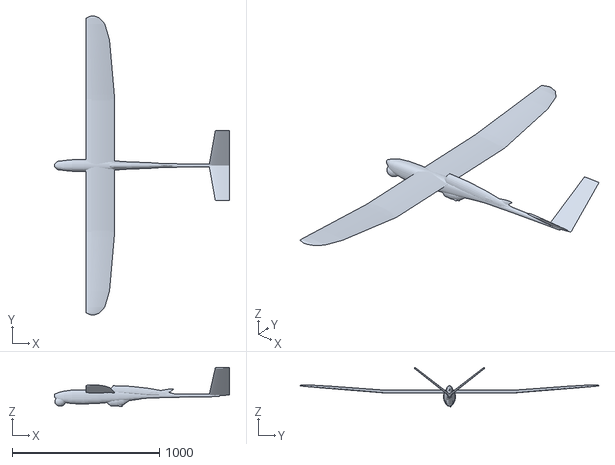
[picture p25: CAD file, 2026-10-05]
models/ff1_stowed.stl
1190.0 x 2028.0 x 266.4

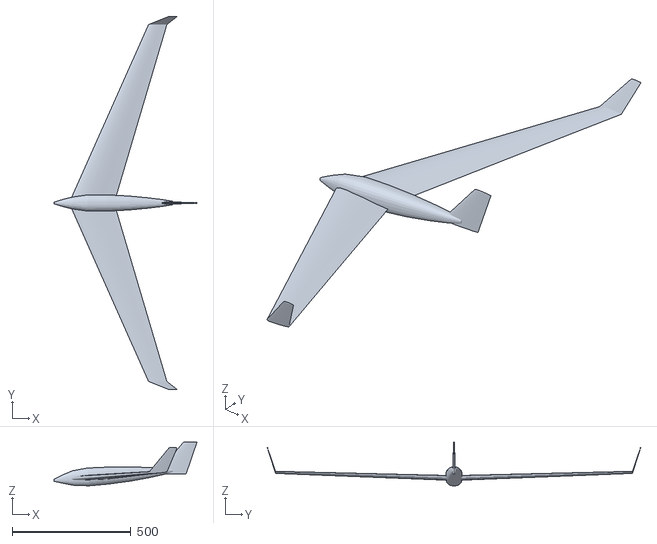
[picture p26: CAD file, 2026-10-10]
models/jetwing/jetwing-1500.stl
600.9 x 1567.5 x 183.6

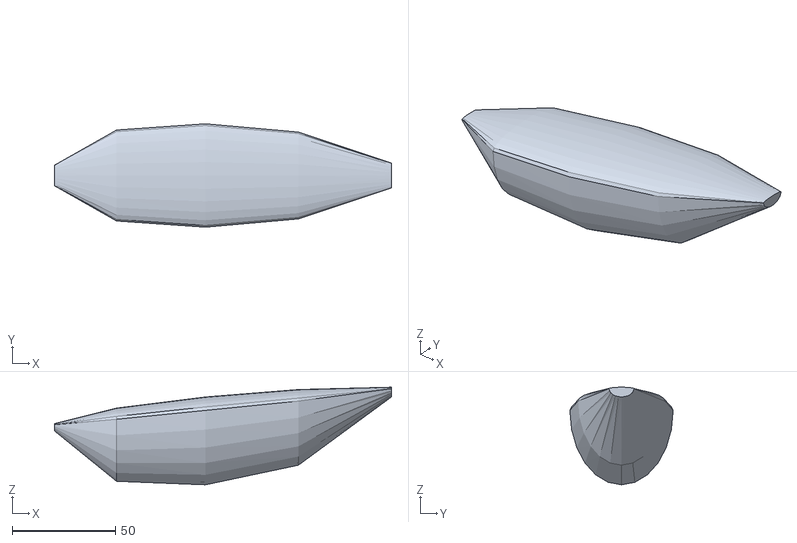
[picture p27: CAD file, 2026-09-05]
models/parts/ventral_fairing.stl
163.0 x 50.0 x 47.2

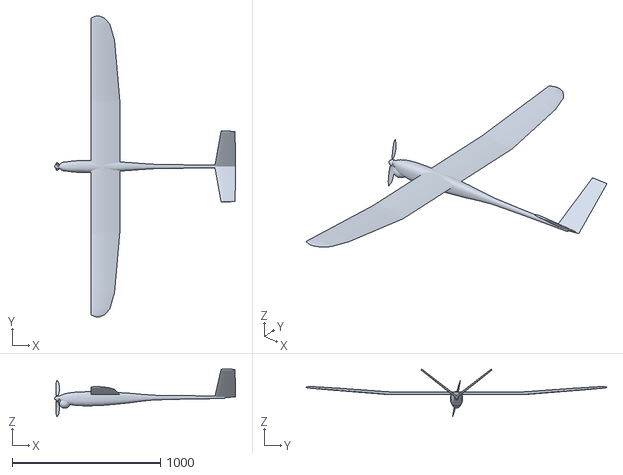
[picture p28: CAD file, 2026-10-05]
models/variants/motor-2000.stl
1220.0 x 2028.0 x 322.5

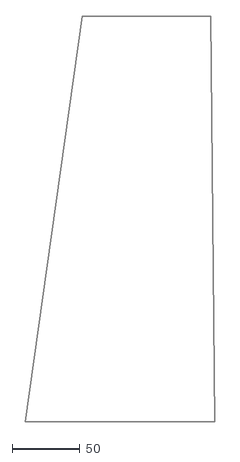
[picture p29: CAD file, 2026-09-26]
plans/dxf/vtail.dxf
140.0 x 300.0

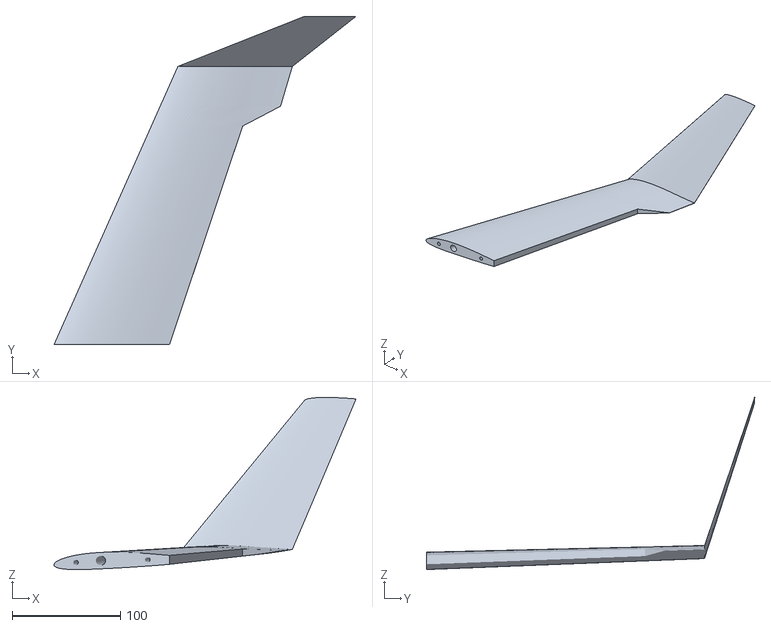
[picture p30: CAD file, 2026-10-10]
print/wing_R4.stl
279.6 x 303.9 x 159.4

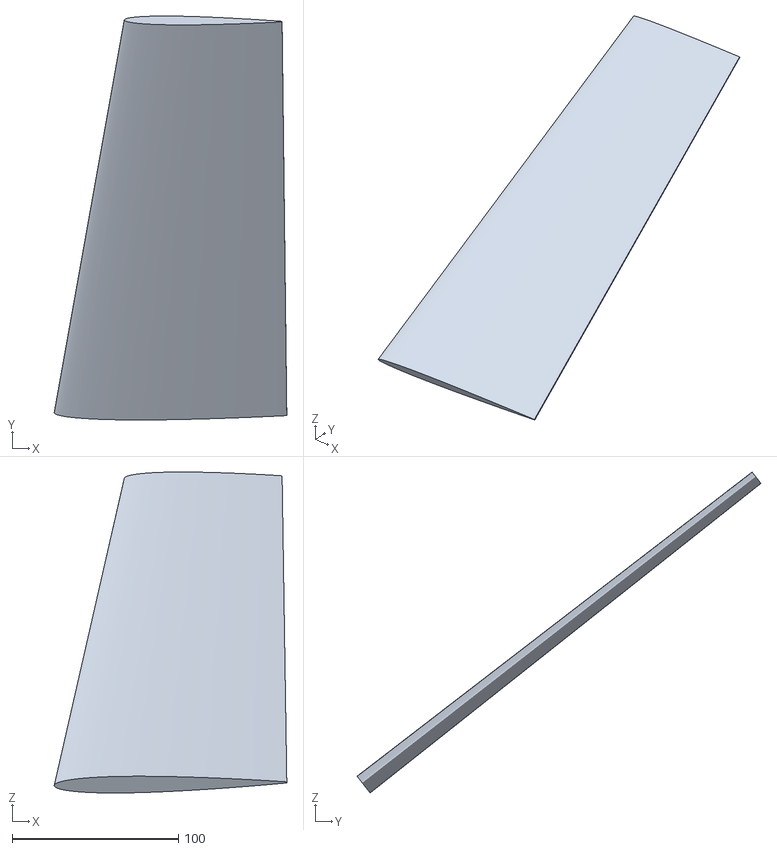
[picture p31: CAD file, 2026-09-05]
models/parts/vtail_starboard.stl
140.0 x 243.0 x 193.1

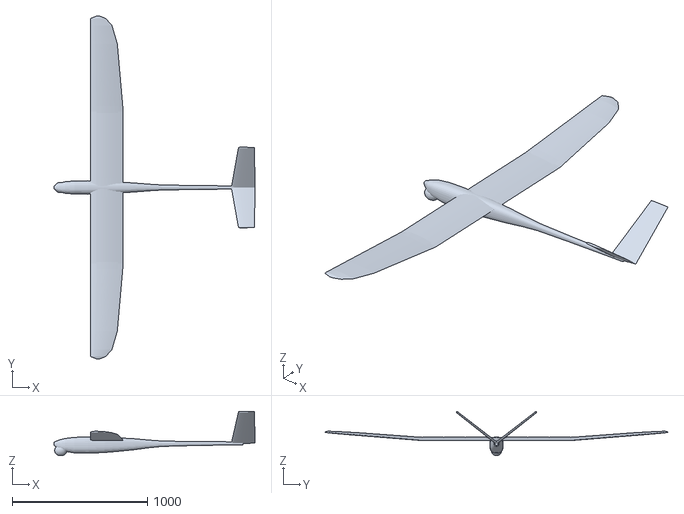
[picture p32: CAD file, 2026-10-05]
models/variants/glider-2500.stl
1487.5 x 2535.0 x 329.0

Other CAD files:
plans/dxf/aerofoil_128mm.dxf
print/flap_L2.stl
models/parts/vtail_port.stl
models/variants/glider-2000.stl
blender/basic_plane.blend
blender/jetwing-parts.blend
blender/jetwing.blend
models/ff1_deployed.obj
models/ff1_stowed.obj
models/jetwing/jetwing-1200.obj
models/jetwing/jetwing-1500.obj
models/parts/dorsal_spine.stl
models/parts/fuselage.stl
models/parts/motor_pod_deployed.stl
models/parts/sensor_turret.stl
models/parts/solar_cells.stl
models/parts/wing_port.stl
models/parts/wing_starboard.stl
models/variants/glider-2000.obj
models/variants/glider-2500.obj
models/variants/motor-2000.obj
models/variants/motor-2500.obj
plans/dxf/aerofoil_160mm.dxf
plans/dxf/aerofoil_195mm.dxf
plans/dxf/aerofoil_92mm.dxf
plans/dxf/formers.dxf
plans/dxf/pod.dxf
plans/dxf/wing.dxf
print/aileron_L1.stl
print/aileron_L2.stl
print/aileron_R1.stl
print/aileron_R2.stl
print/flap_L1.stl
print/flap_R1.stl
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

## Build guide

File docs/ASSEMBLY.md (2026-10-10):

# Building it

2060 mm swept flying wing, 30 printed parts, 50 mm EDF. Target all-up weight
**1124 g** at **29.8 g/dm²**.

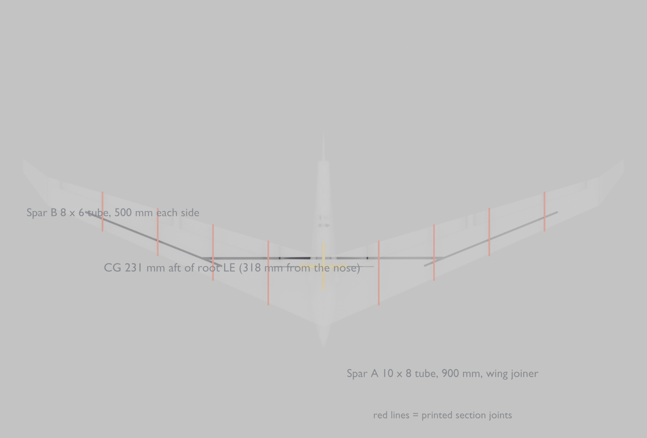
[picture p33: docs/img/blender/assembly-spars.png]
spars


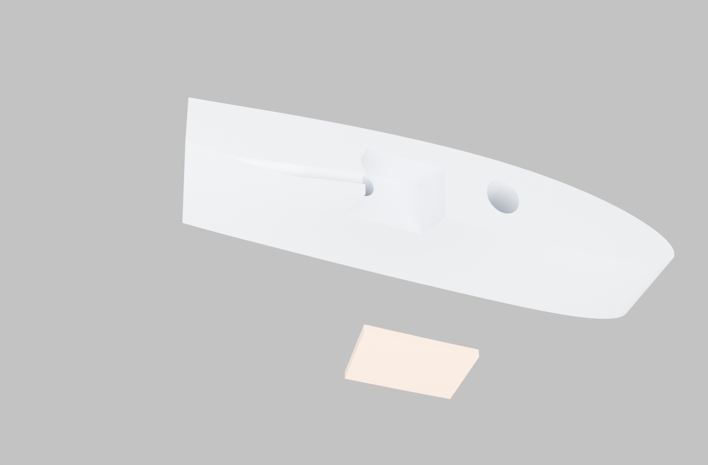
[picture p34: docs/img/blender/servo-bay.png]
servo bays


---

## The one number that matters

**CG: 318 mm back from the nose**, or **231 mm back from the wing root
leading edge** — the same point, measured two ways. Use the root leading edge
if you can; it is a sharp feature and the nose is a curve.

Tolerance **±5 mm**. On a tailless aircraft the CG is not a preference, it is
the difference between an aeroplane and an accident: the neutral point is only
**14.5 mm** behind it. Go aft of that and nothing you do with the sticks will
bring it back.

**Set it nose-heavy for the first flight** — 10 mm forward of the mark. It
will feel slightly reluctant in pitch and want to fly a little fast. That is
what you want. Move it back 3–4 mm at a time afterwards.

---

## What you need besides the prints

### Carbon

| | | |
|---|---|---|
| **Spar A** | 10 × 8 mm tube | **900 mm** — one piece, through the centre |
| **Spar B** | 8 × 6 mm tube | **500 mm** × 2 |
| **Anti-rotation** | 4 mm rod | **380 mm** |
| Dowels | 4 mm rod | ~300 mm, cut into 22 mm pins (you need 12) |

Spar B is 8 mm OD; Spar A is 8 mm ID. **B slides inside A.** That is why those
two sizes and no others.

### Power

| | |
|---|---|
| EDF | 50 mm 12-blade, QF2611 5000KV (fixed, non-retracting) |
| ESC | 40 A minimum, with a **brake-off / coast** setting |
| Battery | 4S 2200 mAh, around 190 g |
| Servos | 4 × 9 g SG90 (wing) + **1 × 9 g MG90S, metal gear** (rudder) |
| Receiver | 6 channel minimum |

### Consumables

30-minute epoxy (spar bonds and joints), thin CA (tacking), 20 mm fibre-reinforced
tape or Blenderm for hinges, sandpaper 240/400, isopropyl alcohol.

---

## Printing

Cut for a **Bambu Lab A2L** (330 x 320 x 325 mm). LW-PLA throughout.
Starting point, not gospel:

| | |
|---|---|
| layer | 0.2 mm, 0.4 mm nozzle |
| walls | 2 perimeters on wing sections, 3 on fuselage |
| infill | 4–6% gyroid in the wing, 0% in the fuselage shells |
| top / bottom | **0 on wing sections** — the perimeters *are* the skin |
| supports | none needed in the orientations supplied |

Open `blender/jetwing-parts.blend` and every part is already standing the way
it prints. Nothing needs rotating.

**Print one wing section first and check the spar slides through** before
committing the rest. `wing_R1` encloses a litre and is a long print — do a
small one, like a hatch, if you only want to check your settings. Bores are cut +0.4 mm oversize; if yours come
out tight, run a 10 mm drill through by hand rather than reprinting.

---

## 1. Wing — dry fit everything first

Lay all **eight** wing sections out in order, both wings, and **thread
Spar A through dry**. No glue yet. Four a side, 257.5 mm each, and the
winglets come already on `wing_R4` / `wing_L4` — there is no separate winglet
to glue on.

1. Slide Spar A through the two root sections (`wing_R1` and `wing_L1`). It
   should pass through both and stand proud 450 mm each side.
2. Add sections 2 and 3 on each side over the protruding spar.
3. Slide **Spar B** in from each tip end — it goes *inside* Spar A for the
   first 70 mm, then carries on out through section 4.
4. Push the whole lot together. Sight down the leading edge from the tip.

**Check now, while you still can:** both panels should show the same dihedral
and the same washout. The tips sit about 36 mm above the root, and each tip
trailing edge sits **2° nose-down** relative to the root. That washout is
designed in and it is what stops the tip stalling before the root — do not
sand it out trying to make the wing "straight".

Only when the dry fit is right:

5. **Epoxy Spar A into the root sections only.** Leave the outboard sections
   dry for now.
6. Fit the **4 mm anti-rotation rod** across the centre at 62% chord. It will
   only go in if both panels are at the same incidence — which is the entire
   reason it is there. If it fights you, something is twisted. Fix that
   before glue.
7. **Thread the servo loom now**, before any wing joint is bonded. The 6 mm
   channel runs from the root out to y = 620 through sections 1, 2 and 3, and
   once those joints are closed you cannot get at it.
8. Working outward one joint at a time: dry pins in, check alignment, then
   epoxy. Two 4 mm dowels per face, 11 mm into each side, either side of the
   spar. Three joints a side.

Bond one joint at a time and let it go off. A wing built in one rush sets
with a twist in it.

---

## 2. Servos

Bays are printed in, so there is nothing to cut. Four of them: one per
control surface, in the **lower** skin, with a matching printed hatch.

| | station | in section | section depth there |
|---|---|---|---|
| flap servo | y = 300 mm | `wing_?2` | 21.0 mm |
| aileron servo | y = 570 mm | `wing_?3` | 17.1 mm |

**The servo lies on its side, output shaft pointing spanwise.** That way the
arm sweeps in a chordwise-vertical plane and drives the surface directly, and
the servo only costs 11.8 mm of section depth instead of 22.7. Mounted the
usual way up it does not fit in this wing at all.

**Why the bays are not under the control surfaces.** At the hinge line there
is only 11–15 mm of section, and a 9 g servo needs 14.8 mm with sensible
walls. So the bays sit at **45% chord** — just aft of the spar, close to
maximum thickness — and a pushrod runs aft to a horn on the surface. The
3.4 mm guide bore is printed in; use 2 mm rod inside a 3 mm tube.

A 9 g servo stops fitting outboard of about y = 730, which is why the aileron
servo sits at the inboard end of its surface rather than the middle.

**The hatch is a separate part and the servo screws to it.** Fit the servo on
the bench, then drop the whole assembly into the bay. Fishing a servo into a
closed pocket through its own hole is the worst job on a build like this, and
it leaves the servo unserviceable afterwards.

**Loom channel.** A 6 mm bore runs spanwise at 50% chord from the aileron bay
inboard to the root, straight through every joint, so the wiring threads
rather than being fished. It passes through both bays on the way, so each
servo lead joins the loom where it sits. The channel is swept along the
section rather than driven straight, and the measured step where one
section's channel meets the next is **0.000 mm**.

Thread the wires **before** you bond the sections together.

### Torque

| surface | worst case | needs | 9 g SG90 gives |
|---|---|---|---|
| aileron | 20° at 20 m/s | 0.29 kg·cm | 1.6 kg·cm ✓ |
| flap | 40° crow at 20 m/s | 1.08 kg·cm | 1.6 kg·cm ✓ |
| **rudder** | 25° at full throttle | **1.82 kg·cm** | **1.6 kg·cm ✗** |

The rudder sits in the EDF efflux, where dynamic pressure is **3060 Pa**
against 245 Pa outside — twelve times. A plastic-gear SG90 is undersized for
it. Use an **MG90S**: same size, same mounting, same bay, about 2.2 kg·cm.

Flap torque is worst with full crow at speed. Deploy crow on approach, around
12 m/s, where it falls to 0.39 kg·cm — not at 20 m/s.

## 3. Hinges

1. Sand the hinge faces lightly. The printed gap is 3 mm each side.
2. Tape hinges: one strip on top with the surface deflected fully down, one
   underneath with it deflected fully up. No slop, no gap for air to leak
   through.
3. Check free movement through the whole range before the servos go in.
4. Horn **in line with the hinge** — an offset horn gives you differential
   you did not ask for.

## 4. Fuselage and EDF

1. Bond `fuselage_1` to `_2` to `_3` nose to tail — three rings of 232 mm.
   These are shells with a 1.2 mm wall; use epoxy sparingly, it is all
   weight. There are no dowels and none are needed: the section is a
   96 x 104 rounded superellipse, not a circle, so each joint keys itself.
2. **Fit the duct, fan and stator before closing the last section.** The
   motor wires come forward inside the duct.
3. Bellmouth inlets bond to the fuselage sides. The rounded lip faces
   forward — it is rounded for a reason, and a sharp or badly-fitted lip
   costs 10–20% of thrust.
4. Set the ESC to **coast, not brake.** A stopped fan is a flat plate across
   the duct and costs about 15% of your glide; freewheeling costs 10%.
5. Fin bonds to the fuselage top. The rudder sits behind the nozzle — that is
   the vectoring, and it is why the fin is that far aft.

---

## 5. Electronics and balance

Battery goes as far forward as it will go. It is the only mass with anywhere
useful to be, and it is how you reach the CG.

| | |
|---|---|
| wing shell + spars | ~510 g |
| fuselage | ~180 g |
| EDF unit | 109 g |
| ESC | 40 g |
| 4S 2200 pack | 190 g |
| 5 servos + RX + wiring | 57 g |
| hatches, horns, pushrods | 12 g |
| hardware, glue | 35 g |
| **total** | **~1120 g** |

**Balance it:** support the wing at 231 mm aft of the root leading edge, one
finger each side of the fuselage, battery fitted and canopy on. It should sit
level or very slightly nose-down.

If it is tail-heavy, move the battery forward. If it will not go far enough
forward, add lead *at the nose*, not amidships — a nose weight does the job
with a quarter of the mass.

---

## 6. Throws

Measured at the trailing edge of each surface, at mid-span.

| | low rate (first flights) | high rate |
|---|---|---|
| **elevator** (all four, together) | ±9 mm | ±14 mm |
| **aileron** (outboard pair) | ±10 mm | ±13 mm |
| **rudder** | ±17 mm | ±27 mm |
| **crow / brake** | flaps 35 mm down, ailerons 10 mm up | — |

Mixing, with a 6-channel set:

- **Elevator** → all four surfaces, same direction
- **Aileron** → outboard pair, opposite directions
- **Flap/crow** → inboard pair down, outboard pair slightly up, on a slider
- **Rudder** → its own channel

Add **15–20% expo** on elevator and aileron. The wing is quick in roll.

**Directions — check before every first flight:**

| stick | surfaces |
|---|---|
| pull back (up elevator) | all four trailing edges go **UP** |
| right aileron | right surface **up**, left **down** |
| right rudder | rudder trailing edge goes **right** |

Get the elevator direction wrong on a flying wing and it is over in two
seconds.

---

## 7. Before the first flight

- [ ] CG at 318 mm from the nose, or 10 mm forward of it
- [ ] Control directions checked on the aircraft, not in your head
- [ ] Throws on **low rate**
- [ ] Both wing panels at the same incidence — sight down from a tip
- [ ] Spar joints fully cured, not just tacky
- [ ] ESC set to coast
- [ ] Range check with the fan running
- [ ] Battery secured — a pack that shifts in flight moves the CG

## 8. First flight

Thrust-to-weight is **0.72**, so it will not climb out vertically. It needs a
proper launch.

Into wind, full throttle, **hard flat throw** slightly nose-down. Do not throw
it upwards — let it accelerate first. It wants about 10 m/s to fly properly
and stalls around **7.5 m/s (27 km/h)**.

Fly it out straight for a few seconds before touching anything but the
elevator. Trim in level flight at about half throttle.

Land it with a long flat approach and the crow brakes in. There is no
undercarriage; it lands on its belly, so pick grass.

---

## If something is wrong in the air

| | |
|---|---|
| **pitches up, feels twitchy, wants to tumble** | tail-heavy — land immediately, move the CG forward |
| **needs constant up elevator, wants to dive** | nose-heavy; add a little up trim, move CG back 3 mm next flight |
| **drops a wing at low speed** | one panel twisted — check incidence against the other |
| **rolls or yaws with throttle** | fan not square in the duct, or inlets unequal |

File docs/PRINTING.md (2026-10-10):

# Printing it on a Bambu Lab A2L

```
python3 blender/print_parts.py      cuts the model up and writes print/*.stl
python3 blender/check_parts.py      audits the STLs before you print them
python3 tools/spar.py               the spar sizing behind the bore diameters
```

parts

Open **`blender/jetwing-parts.blend`** to browse them: every part in print
orientation, named and labelled with its size. Or go straight to the STLs in
`print/`.

**30 parts, every one inside 330 × 320 × 325 mm, every one watertight, none
self-intersecting.**

## What the A2L changes

It is not the plate area that matters, it is the **height**: 325 mm against
the A1's 256. Wing sections print standing on end, so height is span, and
span is what sets the part count.

| | A1 (256³) | A2L (330 × 320 × 325) |
|---|---|---|
| wing sections per side | 5 at 206 mm | **4 at 257.5 mm** |
| root section | split chordwise as well — 260 mm chord on a 256 mm bed | **one piece, square on the plate** |
| winglets | not printable at all | **lofted onto the outboard section** |
| ailerons per side | 3 | **2** |
| flaps per side | 2 | 2 |
| fuselage | 4 rings of 174 mm | **3 rings of 232 mm** |
| parts | 37 | **30** |
| glued joints | 19 | **12** |

Three sections a side would be better still and does not go: 1030 mm of
semi-span in three is 343 mm, and the plate is 325.

The root section is the one that changes character. On the A1 a 260 mm root
chord did not fit a 256 mm bed at all, so it went on the diagonal and then had
to be split chordwise as well. On the A2L it stands square with 60 mm to
spare, as one piece.

### The winglets are new

They were never in the printable set. `jetwing.py` lofts them onto the tip
*inside* the Wing object, and the print sections are generated from the
planform rather than cut out of that object — so nothing ever emitted them.
The aero model had 150 mm winglets and the box had none.

They stay **attached** to the outboard section rather than becoming parts of
their own, and not only because there is room. A winglet is a cantilever in
side load and the tip section is 11 mm thick, so a glued butt joint there is
the worst joint on the aircraft and there is nothing to pin into. Lofted on,
there is no joint to fail. `wing_R4` is 280 × 304 × 159 mm with the winglet
on it.

## How the parts sit

Wing sections print **standing on end, span axis vertical**. That:

- puts the spar bore straight up Z, so it needs no support and comes out round
- lays the layer lines across the chord, where the skin wants them
- makes the limit **325 mm of span**, not of chord

`wing_R4` is the exception worth knowing about: rotating its span up to Z lays
the winglet flat across the plate, which is how a part with a 150 mm winglet
on it fits in 304 mm of height.

Nothing is placed diagonally. The A1 cut *needed* that, and a part that only
fits cornerwise is a part a slicer can quietly place wrong.

## The carbon

Sized in `tools/spar.py` from the actual span loading, not a rule of thumb:
**19.8 N·m of root bending at 9 g ultimate** (6 g limit × 1.5), with the
lift distribution taken from the lifting-line solution for this planform.

| | | |
|---|---|---|
| **Spar A** | 10 × 8 mm tube, **900 mm** | root spar *and* wing joiner, centred |
| **Spar B** | 8 × 6 mm tube, **500 mm**, one per side | inserts 70 mm inside A |
| **Anti-rotation** | 4 mm rod, **380 mm** | across the centre at 62% chord |
| **Joint dowels** | 4 mm rod, **22 mm** each, 12 off | two per joint face |

Spar B is 8 mm OD and Spar A is 8 mm ID, so B **telescopes inside A** — that
is why those two sizes and not any other pair. Bores are cut at **+0.4 mm on
diameter** for a sliding fit after shrinkage; if your printer runs tight,
open them with a drill rather than reprinting.

Why it steps down: the wing gets thin outboard. At the 106 mm tip and 10.5%
thickness there is 11.1 mm of section to put a rod in, and a 10 mm rod leaves
no wall at all. Strength is not the binding constraint past mid-span — room
is. The moment at 80% span is 0.3 N·m, which a 4 mm rod carries easily.

**The anti-rotation rod is not optional.** One round tube, however well
fitted, lets the panels rotate about it, and a wing panel at the wrong
incidence is a wing panel that does not fly.

## Joints

Each joint face carries **two 4 mm dowel holes, 11 mm deep** — up from 3 × 7
on the A1, because the sections are half again as long and the joint carries
more bending. They sit at 14% and 60% chord, either side of the spar at 30%,
so a section cannot rotate while the glue goes off.

Both holes run **parallel to the spar**, not along their own chord lines. The
14, 30 and 60 per cent chord lines each have their own sweep angle: over a
22 mm dowel the 60% line diverges from the spar by 0.49 mm, which is more than
the fit clearance, so three bores each on its own axis would simply refuse to
go together.

| joint | section at 14% c | at 60% c | wall round a 4.4 mm bore |
|---|---|---|---|
| y = 257.5 | 20.3 mm | 17.7 mm | 6.6–8.0 mm |
| y = 515 | 16.8 mm | 14.6 mm | 5.1–6.2 mm |
| y = 772.5 | 13.3 mm | 11.5 mm | 3.6–4.4 mm |

The aft hole used to be specified at 52% chord, which is exactly where the
servo loom channel runs. A 5 mm bore swallows a 3.4 mm dowel hole whole, so
on every joint inboard of y = 620 it would have located nothing. (It would
also have located nothing because the holes were never actually cut — see
below.)

The fuselage rings butt without dowels, and do not need them: the section is
a 96 × 104 rounded superellipse rather than a circle, so each joint keys
itself. There is one way the rings go together and it is obvious by feel.

## The servo loom

A **6 mm channel** runs spanwise at 50% chord from the aileron bay in to the
root, straight through every joint, so you thread the wiring rather than fish
it. It passes deliberately *through* both servo bays, which is what the servo
lead has to do anyway.

It is **swept** along the mid-thickness line, not driven straight between the
ends of each section. The wing is swept and tapered, so the 50% chord line is
not parallel to anything: a single straight cutter across a 257 mm section
sits on 50% chord at both joints and wanders **11.3 mm** off it in the middle.
Swept, it stays mid-section the whole way and meets the next section's channel
with a measured step of **0.000 mm** on a 6 mm bore.

## Parts

```
part                       X       Y       Z   faces  fits A2L?  watertight?
  aileron_L1           105.5   203.0    16.0     802      yes      yes
  aileron_L2            97.7   203.0    14.1     802      yes      yes
  aileron_R1           105.5   203.0    16.0     802      yes      yes
  aileron_R2            97.7   203.0    14.1     802      yes      yes
  flap_L1              115.1   182.4    19.1     802      yes      yes
  flap_L2              108.0   182.4    17.5     802      yes      yes
  flap_R1              115.1   182.4    19.1     802      yes      yes
  flap_R2              108.0   182.4    17.5     802      yes      yes
  fuselage_1           232.0    98.4   108.8     196      yes      yes
  fuselage_2           232.0    98.4   111.9     196      yes      yes
  fuselage_3           232.0    77.8    83.1     170      yes      yes
  hatch_aileron_L       44.1    32.3     4.8      88      yes      yes
  hatch_aileron_R       44.1    32.3     4.8      88      yes      yes
  hatch_flap_L          44.1    32.3     4.5      88      yes      yes
  hatch_flap_R          44.1    32.3     4.5      88      yes      yes
  part_Ducta           197.0    52.0    66.0     171      yes      yes
  part_Ductb           197.0    52.0    64.4     118      yes      yes
  part_Fin             186.7    14.5   202.0     415      yes      yes
  part_Inlet            99.4   125.5    38.5     440      yes      yes
  part_Motor            78.9    26.0    27.6      86      yes      yes
  part_Rudder          139.7    10.6   227.9     422      yes      yes
  part_Stator           21.9    47.5    47.9      98      yes      yes
  wing_L1              303.5   257.5    34.1    1640      yes      yes
  wing_L2              250.1   257.5    30.2    1740      yes      yes
  wing_L3              221.6   257.5    26.3    1587      yes      yes
  wing_L4              279.6   303.9   159.4    2276      yes      yes
  wing_R1              303.5   257.5    34.1    1640      yes      yes
  wing_R2              250.1   257.5    30.2    1740      yes      yes
  wing_R3              221.6   257.5    26.3    1587      yes      yes
  wing_R4              279.6   303.9   159.4    2276      yes      yes

  30 parts, 0 too big for 330x320x325, 0 not watertight
  written to /home/user/Forever-Flight/print/
```

## Check before you print

`blender/check_parts.py` loads every exported STL back in and measures three
things: positive volume in the right ballpark, no non-manifold edges, and **no
two faces passing through each other**.

```
  30 parts, 5553 cm3 of enclosed volume (not filament: the slicer
  hollows these out)
  all parts manifold, positive volume, no self-intersections
```

That last test exists because of what it found. `print_parts.py` had always
checked watertightness and bed fit, and neither catches the failure that
actually occurred: **two wing sections were not wing sections.**

Blender's exact boolean solver has no failure return. Handed a target it
cannot reason about it produces something plausible instead, and here it
returned the *cutter* in place of the part. A 6 mm tube is watertight, it
fits the bed and it slices — so it passed every check and went in the bundle.

The cause was upstream. `section_cut` built the closing strip across the hinge
from the upper surface to the lower one, but appended it *after* the outline
had already arrived at the lower surface. The strip therefore retraced the
hinge line twice and the lofted body intersected itself: **338 self-
intersecting face pairs per section**, invisible in a render, and enough to
make every boolean on the part a coin flip. The A1 cut carried the same bug
and happened to get the right answer.

Three more of the same kind came out of the same audit:

- **Flaps and ailerons were the wrong shape.** They were built by clamping the
  full section's chord into [hinge, 1], which piles every point ahead of the
  hinge onto the hinge line *keeping its own thickness* — so each one carried
  a zero-width flap of surface standing proud of its own hinge face, right up
  to maximum thickness. They measured 30.0 mm deep where the aerofoil says
  19.1, and would have fouled the wing cut-out. Normals inside-out with it,
  and 1,477 self-intersecting pairs in one aileron.
- **The rudder had the same clamp**, from `jetwing.py` this time: 314 pairs,
  and 14.4 mm thick where it should be 10.6.
- **The wing joints had no dowel holes.** The only caller of the function that
  cut them was a spanwise splitter that stopped being used when the sections
  started being generated instead of cut. The docs specified the holes; the
  STLs did not have them.

`boolean()` now checks its own result — a difference cannot halve a face count
or shrink a bounding box — so a silent inversion raises instead of shipping.

## Slicer

For LW-PLA on an A2L, as a starting point rather than gospel:

| | |
|---|---|
| nozzle / layer | 0.4 mm / 0.2 mm |
| walls | 2 perimeters on wing sections, 3 on the fuselage |
| infill | 4–6% gyroid in the wing, 0% in the fuselage shells |
| top/bottom | 0 on wing sections — the perimeters are the skin |
| supports | none needed in these orientations |

The fuselage, duct and inlets are exported as **shells with a real wall**
(1.0–1.2 mm) rather than solid blocks, so the slicer is not hollowing out
something it then has to fill back in.

`wing_R1` encloses a litre. At these settings that is not a litre of filament,
but it is a long print — start it when you have the machine free.

## Assembly order

The full build manual, with the CG, throws and pre-flight checks, is in
[ASSEMBLY.md](ASSEMBLY.md). In short:

1. Thread **Spar A** through both root sections, dry, and check the panels
   sit at the same incidence before any glue.
2. Slide **Spar B** into A from outboard, through sections 2 and 3.
3. Thread the **servo loom** through the 6 mm channel before bonding anything
   — it runs root to y = 620 and you cannot get at it afterwards.
4. Dowel and bond the wing sections outward from the root, one joint at a
   time, checking the tip stays in line. Three joints a side, not five.
5. Fit the **anti-rotation rod** last — it will only go in if the panels are
   already correctly aligned, which is the point of it.
6. Fuselage rings bond nose-to-tail; the duct goes in before the last ring
   closes it up.

## How the parts are made

They are **generated from the parametric loft**, not cut out of the model.
Cutting was tried first and produced nonsense: the wing object is several
lofted runs merged into one mesh, so where two runs abut there are coincident
internal faces, and an exact boolean on a non-manifold mesh returns garbage —
sections came out with the wrong span and chunks missing.

Generating each section from the same maths the skin is made of is manifold
by construction and lands on the surface exactly. The spar bores, servo bays,
pushrod guides, loom channel and dowel holes are then boolean-subtracted,
which works because the sections are clean.

Where a section sits behind a control surface the aft part of the aerofoil
has to stop at the hinge, and the section is **resampled** to the hinge and
closed with a single deliberate edge. Not clamped — clamping is what produced
the wrong-shaped flaps above. And a single edge, with no interior points along
it: points spread along a closing strip are exactly collinear, and a cap
n-gon with a collinear run triangulates into zero-area slivers, which are
self-intersections by another name. Those were the last ones in the bundle.

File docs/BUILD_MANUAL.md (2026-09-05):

# FF-1 *Ember* — build manual

Companion to [DESIGN.md](DESIGN.md). Dimensions come from `tools/config.py`;
regenerate `models/` after any change.

Part numbers below are **examples that meet the requirement**, not
endorsements, and availability moves — treat the requirement column as the
specification and substitute freely.

---

## 1. Bill of materials

### 1.1 Structure

| Qty | Item | Requirement | Example |
|---|---|---|---|
| 1 m² | Biaxial carbon cloth, 80 g/m² ±45° | D-box torsion skin | — |
| 0.5 m² | UD carbon, 115 g/m² | Spar caps, 9 mm tows | T700-based |
| 0.5 m² | Glass cloth, 25 g/m² | Aft skin, shear web | — |
| 1 | XPS or Rohacell block, 60 kg/m³ | Wing cores, hot-wire cut | 1100 × 250 × 60 mm |
| 1 | Carbon boom, tapered 22 → 16 mm | Tail boom, 700 mm | — |
| 1 | Carbon tube, 12 mm × 250 mm | Wing joiner | Pultruded, not rolled |
| 2 | Aluminium joiner sleeve, 12 mm ID | Centre-panel sockets | — |
| 1 set | Epoxy laminating resin, slow hardener | 40–60 min pot life | — |
| 1 | Moulding board / plug stock | Fuselage plug | Tooling foam or MDF |

### 1.2 Energy

| Qty | Item | Requirement | Note |
|---|---|---|---|
| 12 | Monocrystalline cells, 125 mm, ≥ 22 % | Cut into thirds → 36 strips; 34 used | Buy 12 for 11.33 — cutting yield is not 100 % |
| 1 | Tabbing ribbon + flux pen | Low-temperature, thin | Thick ribbon costs drag |
| 6 | Schottky bypass diodes | One per 7 strips | Surface-mount, under the skin |
| 1 m² | ETFE encapsulation film, 50 µm | Optically clear, UV stable | Outermost layer |
| 1 | MPPT, 3 independent channels | 8–14 V in, 12.6 V out, ≥ 40 W total | 3 channels is not optional — see DESIGN §4.1 |
| 3 | Li-ion 21700, ≥ 4.9 Ah, **≥ 10 A continuous** | Series 3S1P | Capacity cells with 7 A ratings will not do |
| 1 | 3S BMS with balance | ≥ 15 A, low quiescent | |
| 1 | Fuse, 15 A, and an XT30 main disconnect | | |

### 1.3 Propulsion and recovery

| Qty | Item | Requirement | Note |
|---|---|---|---|
| 1 | Brushless outrunner, ~500 Kv, ≤ 55 g | Motor, 3S | 480–540 Kv acceptable |
| 1 | ESC, 30 A, **bidirectional / regen capable** | Motor drive | |
| 1 | Folding prop 10 × 6 + spinner + hub | 254 mm | Carbon blades |
| 1 | Brushless outrunner, ~380 Kv, ≤ 50 g | Turbine generator | 350–420 Kv; a rewound gimbal motor works |
| 1 | FOC controller with regen | Turbine → 12 V bus | VESC-class mini |
| 1 | Turbine rotor, 150 mm, 4 folding blades | Custom; see §4 | |
| 2 | Metal-gear micro servo, ≥ 3.5 kg·cm, ≤ 14 g | Pylon and turbine actuation | |
| 1 set | 4-bar linkage hardware | 2 mm carbon links, M2 clevises, over-centre stop | Motor pylon |
| 1 | **Micro linear actuator** | 50 mm stroke, ≥ 80 N, **self-locking** ratio, ≤ 45 g | L12-50-210:1 class — see [VERTICAL_MAST.md](VERTICAL_MAST.md) §5.2 |
| 1 set | Square carbon tube, 0.8 mm wall | 34×22, 30.4×18.4, 26.8×14.8, 23.2×11.2 mm | Mast trunk + 3 stages |
| 8 | PTFE-lined bushing strips | μ ≤ 0.12 on hard-anodised | Two per telescoping joint |
| 2 | Pinion, module 0.4, Ø8 mm | With 4 matching racks | Rack–pinion–rack doublers |
| 1 set | Bellcrank, con-rod, M2 pivots | Equal 30 mm arms, 90° apart | |
| 2 | Hall sensor + magnet | Mast end-of-travel confirmation | Independent of the actuator's own feedback |

### 1.4 Avionics and payload

| Qty | Item | Requirement |
|---|---|---|
| 1 | Flight controller, ArduPlane-compatible wing board | F405 or H743 class, integrated baro |
| 1 | Airspeed sensor + pitot | **Essential** — the soaring controller needs energy rate |
| 1 | GNSS + magnetometer | SBAS capable |
| 1 | LoRa telemetry modem, 868/915 MHz | BVLOS command and hotspot reporting |
| 1 | Control link RX | Test phase; keep it fitted |
| 4 | Wing/tail servo, ≤ 9 g, metal gear | 2 aileron, 2 ruddervator |
| 2 | Wing servo, ≤ 9 g | Flaps (optional, recommended) |
| 1 | LWIR radiometric core, 160 × 120, 8–14 µm | Radiometric output is required, not just imagery |
| 1 | Visible camera module | Smoke cross-check |
| 1 | Low-power SBC | Event-triggered inference |

---

## 2. Tooling

Hot-wire cutter with the FF-SC1 templates (generate with `tools/build_model.py`
and cut from 1.5 mm ply or aluminium). Vacuum bagging setup — a 30 kPa pump is
enough and gentler on the cells than a strong one. Digital scale reading to
0.1 g; you will use it constantly. A 1.5 m flat reference table.

---

## 3. Construction sequence

Weigh every component before and after installation and record it against the
mass table in [ANALYSIS.md](ANALYSIS.md) §1. A build that tracks its budget
lands at 1622 g; one that does not lands at 1900 g and loses hours of
endurance.

### Stage 1 — Wing cores and spar

1. Hot-wire the five core sections (centre pair, inner pair, outer pair) from
   the templates. Mind the washout: −1.4° at y = 850, −2.0° at the tip.
2. Route the spar trench at 30 % chord, full depth, through all cores.
3. Lay up the spar caps directly in the trench: 3 plies at the root, dropping
   to 2 at 45 % semi-span and 1 at 70 %. **Step the plies, do not sand a
   taper** — sanded UD loses its fibre continuity exactly where you need it.
4. Bond the vertical shear web (45/45 glass) between the caps.
5. Cure under vacuum on the flat table with the cores in their cradles.

### Stage 2 — D-box and skin

6. Lay the ±45° biaxial carbon over the leading edge, wrapping to the spar top
   and bottom. This carries the torsion.
7. Skin aft of the spar with 25 g/m² glass.
8. **Rout the cell recesses** — 0.4 mm deep, matching the strip layout in
   `models/geometry.json`. Recessing the cells rather than laying them proud
   is worth roughly half the 0.0012 cell-step drag increment.
9. Wet-sand to 600 grit, then 1200. At Re ≈ 110 000 this matters more than
   almost anything else you can do.

### Stage 3 — Array

10. Cut cells into thirds with a laser or a diamond scribe. Expect breakage;
    that is why the BOM says 12 cells for 11.33.
11. Tab strips in **three independent strings**, series within a string.
    Fit bypass diodes every 7 strips.
12. Dry-fit the whole array before bonding anything. Check every strip sits
    flat in its recess with no rock.
13. Bond with a thin, flexible optically-clear adhesive. Do not use a rigid
    epoxy — it transfers skin strain straight into the silicon.
14. Encapsulate with ETFE, vacuum-bagged at low pressure. Seal the edges.
15. **Electroluminescence-image the array** before the wing ever flies, and
    keep the image. It is your only way to see a crack.

### Stage 4 — Fuselage

16. Plug, mould, then lay up the pod in Kevlar/carbon. Kevlar on the outer
    plies of the belly — it survives belly landings that carbon does not.
17. Bond the spar box at x = 250–300 mm, square to the fuselage datum and
    with 1.5° of wing incidence built in.
18. Cut the dorsal bay (x = 385–790) and the ventral bay (x = 350–575).
    Reinforce both openings with a carbon rim; you have just cut the two
    highest-stress regions of the shell.
19. Bond the boom, checking the V-tail incidence at −1.0° against the wing.

### Stage 5 — Mechanisms

20. Build the pylon 4-bar as a sub-assembly on the bench. Set the over-centre
    stop so the linkage locks 2° past top-dead-centre at full deployment.
21. Cycle it 200 times by hand before installation. Anything that will bind,
    binds in the first 200 cycles.
22. Build the turbine swing arm. Proof-load the folding blade hinges to **3×
    the calculated centrifugal load at 7000 rpm** before you ever spin it.
23. Balance the rotor statically, then dynamically. A 150 mm rotor at 6400 rpm
    is a serious object.
24. Fit bay doors, cammed off each linkage. Verify the doors cannot be open
    with the pod stowed.

### Stage 6 — Systems

25. Wire the 12 V bus as a star from the BMS, not a daisy chain.
26. Route the three MPPT string pairs through the wing joiner as twisted
    pairs. Solar strings are a noise source next to the magnetometer — keep
    them 100 mm clear of it and twist them.
27. Mount the battery on the sliding tray. Do not glue it down; it is the CG
    trim mechanism.
28. **Meter every rail on the bench** and compare to the 7.9 W hotel budget in
    [ANALYSIS.md](ANALYSIS.md) §5.3 before the first flight.

---

## 4a. Deployment mast

Build and rig it per [VERTICAL_MAST.md](VERTICAL_MAST.md) §8. In short: bond
the trunk between two bulkheads and never into the shell; cycle the assembled
mast 200 times dry before it goes in the aircraft; set the rack mesh with the
stages fully extended; and ping-test the extended mast, recording the
frequency, before the first spin-up.

## 4. Turbine rotor

The one part with no off-the-shelf equivalent.

| | |
|---|---|
| Diameter | 150 mm |
| Blades | 4, folding |
| Hub radius | 15 mm |
| Chord | 22 mm at the root, 15 mm at mid, 9 mm at the tip |
| Twist | 36° at r/R = 0.2 falling to about 11° at the tip |
| Section | Thin cambered plate, 9 % thick, 3.5 % camber |
| Design point | λ = 2.5, C_p 0.36 |

Blade geometry is generated by `build_turbine()` in `tools/build_model.py` and
exported to `models/parts/rat_pod_deployed.stl`. Print the blades in a tough
filament for ground testing; make the flight set from carbon-filled nylon or
lay them up in carbon over a printed core.

The high twist is deliberate. A turbine blade at low tip-speed ratio sees a
very different inflow angle at the root than at the tip, and an untwisted
blade will be stalled inboard and windmilling outboard.

---

## 5. Setup and first-flight configuration

### Balance
CG at **277 mm aft of the nose** (34.2 % MAC, 20 % static margin). Set it with
both pods **stowed**, wing level, on the spar-box datum. Slide the battery
tray; do not add ballast until the tray is at an end stop.

### Control throws (starting points)
| Surface | Throw | Expo |
|---|---|---|
| Aileron | ±14 mm, 35 % differential | 30 % |
| Ruddervator (pitch) | ±9 mm | 35 % |
| Ruddervator (yaw) | ±12 mm | 25 % |
| Flap | 0 / −6 / −14 mm (cruise / thermal / landing) | — |

### ArduPlane
Set the airspeed sensor up first and confirm it against a measured glide.
Then `SOAR_ENABLE = 1`, `SOAR_VSPEED = 0.7`, `SOAR_ALT_MIN = 250`,
`SOAR_ALT_MAX = 900`, and enter the sink polar from
[ANALYSIS.md](ANALYSIS.md) §2.3 into the `SOAR_POLAR_*` parameters.

### Interlocks to verify on the bench, every time
1. Mast retracts fully below 25 m AGL — **test the hardware failsafe with the
   scripting engine deliberately halted.**
2. Turbine will not engage below 14 m/s; the mast will not move above 20 m/s.
3. Rotor is electrically braked before any retract command is accepted.
4. Bay doors cannot be commanded open with the mast stowed.
5. Pylon over-centre lock holds with the servo unpowered.
6. **Mast holds full air load with the actuator unpowered** — this is the only
   thing keeping it up in flight. Load the extended mast to 2 N at the nacelle
   with power removed and confirm zero creep over 10 minutes.

### Launch and recovery
Hand launch or bungee, both pods stowed, flaps at −6 mm. There is no landing
gear: land on the belly skid, wings level, both pods stowed, into wind. Approach
with the turbine as the airbrake only above 25 m AGL — below that it must be up.

---

## 6. Regenerating everything

```bash
python3 tools/build_model.py   # models/: STL, OBJ, geometry.json
python3 tools/analysis.py      # docs/ANALYSIS.md
python3 tools/render.py        # docs/img/: three-views
```

All three read `tools/config.py`. Change a dimension there and everything —
model, drawings, mass budget, polar, energy budget, detection performance —
regenerates consistently.

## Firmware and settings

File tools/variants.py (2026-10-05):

#!/usr/bin/env python3
"""
Airframe variants of the FF-1, exported as 3D files.

    python3 tools/variants.py

Builds the aircraft as the printed plans actually produce it -- no retractable
motor pylon, no retractable turbine mast, and therefore no dorsal spine and no
keel fairing, because those two exist only to swallow the retracting pods.

Four variants:

    glider-2000   2.0 m span, no motor               pure glider
    motor-2000    2.0 m span, nose folding prop      self-launching
    glider-2500   2.5 m span, no motor
    motor-2500    2.5 m span, nose folding prop

The 2500 variants are the whole aircraft scaled by 1.25, not a longer wing on
the same fuselage. Geometric scaling keeps the tail volume coefficients and the
CG position (as a fraction of mean chord) exactly where they are, so the
aircraft stays trimmed and stable. Stretching only the span would cut the fin
volume by a third and leave it directionally soft -- see the table this prints.
"""

from __future__ import annotations

import math
import os
import sys

sys.path.insert(0, os.path.dirname(os.path.abspath(__file__)))

import analysis as AN
import build_model as B
import config as C
import mesh as M
import plans as PL

ROOT = os.path.dirname(os.path.dirname(os.path.abspath(__file__)))
OUT = os.path.join(ROOT, "models", "variants")
IMG = os.path.join(ROOT, "docs", "img", "variants")

VARIANTS = [
    ("glider-2000", 1.00, "none", "2.0 m glider, no motor"),
    ("motor-2000",  1.00, "nose", "2.0 m, nose folding prop"),
    ("glider-2500", 1.25, "none", "2.5 m glider, no motor"),
    ("motor-2500",  1.25, "nose", "2.5 m, nose folding prop"),
]

# How each mass line scales with a geometric factor k.
#   3 = solid structure (volume)   2 = skins and films (area)   0 = bought gear
MASS_EXP = {
    "Wing cores, XPS 30 kg/m3": 3,
    "Wing skin: 25 g/m2 glass or laminating film": 2,
    "Wing spar, 8 mm carbon tube + joiner": 3,
    "Control surfaces, hinges, horns": 2,
    "Fuselage pod, 3 mm depron + ply doublers": 2,
    "Tail boom, 16-12 mm carbon, 700 mm": 2,
    "V-tail panels + mount": 2,
    "Motor, ESC, folding prop (nose)": 0,
    "Battery, 3S 2200 mAh LiPo": 0,
    "RX, 4 servos, wiring": 0,
    "Flight controller, GNSS, airspeed": 0,
}


def variant_mass(scale, motor):
    """Grams, and the itemised breakdown."""
    rows, total = [], 0.0
    for name, g in PL.PROTO_MASS:
        if motor == "none" and name.startswith("Motor,"):
            continue
        gs = g * scale ** MASS_EXP.get(name, 2)
        rows.append((name, gs))
        total += gs
    return total, rows


def variant_cd0(motor):
    """C_D0 built up from the design components, corrected for this airframe."""
    keep = []
    for (n, d, note) in C.DRAG["components"]:
        if "spine" in n.lower() or "ventral" in n.lower():
            continue                      # deleted with the retracting pods
        if "bay door" in n.lower():
            continue                      # no bays
        keep.append((n, d, note))
    base = C.DRAG["wing_cd_min"] + sum(d for _n, d, _t in keep)
    base -= 0.00120                        # no solar cells, so no cell steps
    base += 0.00850                        # foam build: surface, LE radius, linkages
    if motor == "nose":
        base += 0.00030                    # folded blades against the spinner
    return base * (1.0 + C.DRAG["margin"])


def performance(scale, motor):
    """Key numbers for a variant, from the design model."""
    mass_g, _rows = variant_mass(scale, motor)
    mass = mass_g / 1000.0
    W = mass * C.MISSION["g"]
    cd0 = variant_cd0(motor)
    g = AN.geom()
    S = g["S"] * scale ** 2
    b = g["b"] * scale
    # Geometric scaling means EVERYTHING scales -- tail included. Scaling the
    # wing alone is a span stretch, and it is what collapses the tail volumes.
    saved = (C.DRAG["components"], C.DRAG["margin"], C.WING["span"],
             [list(r) for r in C.WING["stations"]],
             {k: C.VTAIL[k] for k in ("le_x", "root_chord", "tip_chord",
                                      "panel_span")})
    try:
        C.DRAG["components"] = [("variant", cd0 / (1 + C.DRAG["margin"])
                                 - C.DRAG["wing_cd_min"], "")]
        C.DRAG["margin"] = 0.0
        C.WING["span"] = C.WING["span"] * scale
        C.WING["stations"] = [(y * scale, c * scale, x * scale, d, t)
                              for (y, c, x, d, t) in C.WING["stations"]]
        for k in ("le_x", "root_chord", "tip_chord", "panel_span"):
            C.VTAIL[k] = C.VTAIL[k] * scale
        kp = AN.key_points(W)
        pms = AN.practical_min_sink(W)
        st = AN.stability()
        return {"mass_g": mass_g, "cd0": cd0, "S": S, "b": b,
                "wing_loading": W / S, "ld": kp["best_glide"]["LD"],
                "v_bg": kp["best_glide"]["V"], "v_stall": kp["v_stall"],
                "sink_min": pms["sink"], "v_ms": pms["V"],
                "mac": AN.geom()["mac"], "vh": st["V_h"], "vv": st["V_v"],
                "cg_mac": st["cg_target"], "np_mac": st["x_np_mac"]}
    finally:
        (C.DRAG["components"], C.DRAG["margin"], C.WING["span"],
         stations, vt) = saved
        C.WING["stations"] = [tuple(r) for r in stations]
        C.VTAIL.update(vt)


def span_stretch_check():
    """What a span-only stretch would do to the tail volumes. For the notes."""
    saved = [list(r) for r in C.WING["stations"]]
    span0 = C.WING["span"]
    base = AN.stability()
    try:
        k = 1.25
        # add span at the existing taper, leaving fuselage and tail alone
        C.WING["span"] = span0 * k
        C.WING["stations"] = [(y * k, c, x, d, t)
                              for (y, c, x, d, t) in C.WING["stations"]]
        stretched = AN.stability()
        g = AN.geom()
        return {"base_vh": base["V_h"], "base_vv": base["V_v"],
                "str_vh": stretched["V_h"], "str_vv": stretched["V_v"],
                "str_S": g["S"], "str_AR": g["AR"]}
    finally:
        C.WING["span"] = span0
        C.WING["stations"] = [tuple(r) for r in saved]


def build(name, scale, motor, solar=True, turret=True):
    saved = dict(B.OPTS)
    try:
        B.OPTS.update({"motor": motor, "turbine": False, "spine": False,
                       "ventral": False, "solar": solar, "turret": turret,
                       "panel_lines": True})
        a, props, _m, _r = B.assemble(True)
    finally:
        B.OPTS.clear()
        B.OPTS.update(saved)          # never leak variant state to a later caller
    if scale != 1.0:
        a.apply(M.scale(scale))
    return a, props


def render_variant(a, name, scale):
    import render as R
    R.render(a, R.iso(35, -20), w=1200, h=780,
             path=os.path.join(IMG, name + ".png"))
    return os.path.join(IMG, name + ".png")


def render_size_comparison(meshes):
    """Both spans in ONE frame, so the size difference is actually visible.

    Rendered separately each image auto-fits and the two look identical.
    """
    import render as R
    scene = M.Mesh("compare")
    small = meshes["motor-2000"].copy()
    big = meshes["motor-2500"].copy()
    big.apply(M.translate(1750.0, 0.0, 0.0))
    scene.merge(small, group_name="motor_pod")
    scene.merge(big, group_name="wing_stbd")
    path = os.path.join(IMG, "size-comparison.png")
    R.render(scene, lambda p: (p[1], -p[0], p[2]), w=1250, h=980, path=path)
    return path


def main():
    os.makedirs(OUT, exist_ok=True)
    os.makedirs(IMG, exist_ok=True)
    rows, meshes = [], {}
    for (name, scale, motor, desc) in VARIANTS:
        a, _props = build(name, scale, motor)
        meshes[name] = a
        stl = os.path.join(OUT, name + ".stl")
        obj = os.path.join(OUT, name + ".obj")
        M.write_stl(a, stl, f"FF-1 {name}")
        M.write_obj(a, obj, name)
        p = performance(scale, motor)
        lo, hi = a.bounds()
        render_variant(a, name, scale)
        rows.append((name, desc, p, len(a.f), hi[1] - lo[1], hi[0] - lo[0]))
        print(f"{name:<13s} {len(a.f):>6d} tris  span {hi[1] - lo[1]:.0f} mm  "
              f"length {hi[0] - lo[0]:.0f} mm  "
              f"{os.path.getsize(stl) / 1024:.0f} kB")

    print()
    print(f"{'variant':<13s} {'mass':>7s} {'W/S':>9s} {'stall':>7s} "
          f"{'L/D':>6s} {'min sink':>9s} {'V_h':>6s} {'V_v':>7s} {'CG':>7s}")
    for (name, desc, p, _t, _b, _l) in rows:
        print(f"{name:<13s} {p['mass_g']:>6.0f}g "
              f"{p['wing_loading'] / C.MISSION['g'] * 10:>7.1f} g/dm2 "
              f"{p['v_stall']:>6.1f} {p['ld']:>6.1f} "
              f"{p['sink_min']:>8.2f}  {p['vh']:>5.2f} {p['vv']:>6.3f} "
              f"{p['cg_mac'] * 100:>6.1f}%")

    print("wrote", os.path.relpath(render_size_comparison(meshes), ROOT))
    s = span_stretch_check()
    print()
    print("Why the 2500 is a whole-aircraft scale, not a longer wing:")
    print(f"  geometric scale x1.25   V_h {rows[2][2]['vh']:.3f}  "
          f"V_v {rows[2][2]['vv']:.4f}   (unchanged - stays trimmed)")
    print(f"  span stretch to 2.5 m   V_h {s['str_vh']:.3f}  "
          f"V_v {s['str_vv']:.4f}   on the same fuselage and tail")
    print(f"  targets                 V_h 0.45-0.70     V_v 0.020-0.035")
    return rows


if __name__ == "__main__":
    main()

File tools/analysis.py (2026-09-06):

#!/usr/bin/env python3
"""
Forever-Flight FF-1 performance, energy, stability and payload analysis.

Everything the design documents quote is computed here, from tools/config.py,
and written to docs/ANALYSIS.md. Nothing in the docs is hand-typed physics.

Run:  python3 tools/analysis.py
"""

from __future__ import annotations

import math
import os
import sys

sys.path.insert(0, os.path.dirname(os.path.abspath(__file__)))

import build_model as B
import config as C

ROOT = os.path.dirname(os.path.dirname(os.path.abspath(__file__)))
G = C.MISSION["g"]
RHO = C.MISSION["rho_cruise"]
NU = C.MISSION["nu"]


# ==========================================================================
# mass and geometry
# ==========================================================================

def mass_rollup():
    groups, total, var = {}, 0.0, 0.0
    for (grp, item, g, unc) in C.MASS:
        groups.setdefault(grp, []).append((item, g, unc))
        total += g
        var += unc * unc
    growth = total * C.MASS_GROWTH_ALLOWANCE
    return {"groups": groups, "itemised_g": total, "growth_g": growth,
            "mtow_g": total + growth, "sigma_g": math.sqrt(var)}


def geom():
    stns = B.wing_geometry()
    S = B.planform_area_mm2(stns) / 1e6
    b = C.WING["span"] / 1000.0
    mac = B.mean_aero_chord(stns) / 1000.0
    v = C.VTAIL
    S_v_panel = 2 * (v["panel_span"] / 1000.0) * \
        ((v["root_chord"] + v["tip_chord"]) / 2.0 / 1000.0)
    dih = math.radians(v["dihedral"])
    S_h = S_v_panel * math.cos(dih) ** 2
    S_vert = S_v_panel * math.sin(dih) ** 2
    x_le_root = C.WING["stations"][0][2] / 1000.0
    x_ac_w = x_le_root + 0.25 * mac
    x_ac_t = (v["le_x"] + 0.25 * (v["root_chord"] + v["tip_chord"]) / 2.0) / 1000.0
    return {"S": S, "b": b, "AR": b * b / S, "mac": mac,
            "S_tail_wetted": S_v_panel, "S_h": S_h, "S_v": S_vert,
            "x_ac_w": x_ac_w, "x_ac_t": x_ac_t,
            "b_h": 2 * (v["panel_span"] / 1000.0) * math.cos(dih)}


# ==========================================================================
# drag build-up and polar
# ==========================================================================

def cd0_buildup():
    rows = [("Wing profile (at design CL)", C.DRAG["wing_cd_min"],
             f"Re ~ {int(120000/1000)*1000:,}, SD7037-class section")]
    rows += [(n, d, note) for (n, d, note) in C.DRAG["components"]]
    raw = sum(r[1] for r in rows)
    margin = raw * C.DRAG["margin"]
    return rows, raw, margin, raw + margin


def cd0_clean():
    return cd0_buildup()[3]


def polar(CL, cd0=None, motor=False, rat=False):
    g = geom()
    cd0 = cd0_clean() if cd0 is None else cd0
    cd0 += C.DRAG["motor_deployed_off"] if motor else 0.0
    cd0 += C.DRAG["rat_deployed_feathered"] if rat else 0.0
    cdp = C.DRAG["wing_cd_k"] * (CL - C.DRAG["wing_cl_design"]) ** 2
    cdi = CL * CL / (math.pi * g["AR"] * C.DRAG["oswald_e"])
    return cd0 + cdp + cdi


def speed_for_cl(CL, W, S, rho=RHO):
    return math.sqrt(2.0 * W / (rho * S * CL))


def sweep(W, motor=False, rat=False, rho=RHO):
    g = geom()
    out = []
    cl = 0.15
    while cl <= C.DRAG["cl_max"] + 1e-9:
        cd = polar(cl, motor=motor, rat=rat)
        V = speed_for_cl(cl, W, g["S"], rho)
        ld = cl / cd
        sink = V / ld
        out.append({"CL": cl, "CD": cd, "V": V, "LD": ld, "sink": sink,
                    "P_aero": W * sink,
                    "Re": V * g["mac"] / NU})
        cl += 0.01
    return out


def key_points(W, motor=False, rat=False):
    s = sweep(W, motor=motor, rat=rat)
    best_glide = max(s, key=lambda r: r["LD"])
    min_sink = min(s, key=lambda r: r["sink"])
    g = geom()
    v_stall = speed_for_cl(C.DRAG["cl_max"], W, g["S"])
    v_stall_flap = speed_for_cl(C.DRAG["cl_max_flapped"], W, g["S"])
    return {"best_glide": best_glide, "min_sink": min_sink,
            "v_stall": v_stall, "v_stall_flapped": v_stall_flap, "sweep": s}


def elec_power_for(V, W, motor=True, rat=False):
    """Electrical watts to hold level flight at V."""
    g = geom()
    CL = 2.0 * W / (RHO * g["S"] * V * V)
    if CL > C.DRAG["cl_max"]:
        return None, CL
    CD = polar(CL, motor=motor, rat=rat)
    D = 0.5 * RHO * g["S"] * V * V * CD
    p_aero = D * V
    e = C.EFF
    return p_aero / (e["prop"] * e["motor"] * e["esc"]), CL


# ==========================================================================
# turbine ("dynamo") physics
# ==========================================================================

def rat_power(V, rho=RHO):
    """Shaft and electrical watts, and the drag the extraction costs."""
    r = C.RAT
    A = math.pi * (r["rotor_dia"] / 2000.0) ** 2
    p_air = 0.5 * rho * A * V ** 3
    p_shaft = p_air * r["cp"]
    p_elec = p_shaft * C.EFF["generator"] * C.EFF["rectifier_charger"]
    return {"V": V, "disc_area_m2": A, "p_available": p_air,
            "p_shaft": p_shaft, "p_elec": p_elec,
            "extraction_drag_N": p_shaft / V,
            "rpm": r["lambda_design"] * V / (r["rotor_dia"] / 2000.0) * 60 / (2 * math.pi)}


def regen_descent(W, V, dh_m):
    """Energy recovered by descending dh_m with the turbine on, vs gliding."""
    g = geom()
    rp = rat_power(V)
    CL = 2.0 * W / (RHO * g["S"] * V * V)
    CD = polar(CL, motor=False, rat=True)
    D_air = 0.5 * RHO * g["S"] * V * V * CD
    p_air = D_air * V
    frac = rp["p_shaft"] / (rp["p_shaft"] + p_air)
    pe = W * dh_m                                     # potential energy, J
    recovered_J = pe * frac * C.EFF["generator"] * C.EFF["rectifier_charger"]
    sink = (p_air + rp["p_shaft"]) / W
    return {"V": V, "dh_m": dh_m, "pe_wh": pe / 3600.0,
            "recovered_wh": recovered_J / 3600.0,
            "recovery_frac": recovered_J / pe,
            "sink_ms": sink, "descent_time_s": dh_m / sink,
            "turbine_share": frac, "p_elec": rp["p_elec"]}


def rat_hold_altitude(W, V):
    """Lift rate needed to hold height at V with the turbine extracting."""
    g = geom()
    rp = rat_power(V)
    CL = 2.0 * W / (RHO * g["S"] * V * V)
    CD = polar(CL, motor=False, rat=True)
    p_air = 0.5 * RHO * g["S"] * V ** 3 * CD
    return {"V": V, "p_elec": rp["p_elec"],
            "thermal_needed_ms": (p_air + rp["p_shaft"]) / W,
            "glide_sink_ms": p_air / W}


# ==========================================================================
# solar
# ==========================================================================

def solar_elevation(lat_deg, doy, hour_solar):
    dec = math.radians(23.45) * math.sin(2 * math.pi * (284 + doy) / 365.0)
    H = math.radians(15.0 * (hour_solar - 12.0))
    lat = math.radians(lat_deg)
    s = (math.sin(lat) * math.sin(dec) + math.cos(lat) * math.cos(dec) * math.cos(H))
    return math.degrees(math.asin(max(-1.0, min(1.0, s))))
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

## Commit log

2026-09-05 Add FF-1 Ember parametric model, geometry generator and analysis toolchain
    Dependency-free Python toolchain for a 2 m span solar/soaring wildfire
    surveillance glider with a retractable motor pylon and a retractable
    energy-recovery turbine.
    - tools/mesh.py triangle mesh kernel, STL and OBJ writers
    - tools/airfoil.py NACA 4-digit generator plus a curvature-limiting
    "solar flattening" morph so cut cells can be bonded
    to the upper surface without micro-cracking
    - tools/config.py single source of truth for every dimension and mass
    - tools/build_model.py lofted airframe, deployable pods, solar cell layout
    - tools/analysis.py drag build-up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
    [dorsal_spine.stl, ff1_deployed.obj, ff1_deployed.stl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]
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2026-09-05 Add interactive 3D viewer
    Riggable web export of the same geometry the STLs come from: the pods
    leave in their own local frames and the blades as raw radial meshes, so
    the browser composes the deployment travel rather than replaying a
    baked animation. Vertices quantised to int16 over the model bounding
    box, base64'd, inlined at build time because the Artifact CSP blocks
    fetch.
    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
    [ff1_deployed.obj, ff1_deployed.stl, ff1_stowed.obj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]
2026-09-05 Replace the turbine swing arm with VDM-1, a vertical telescoping mast
    The pivoting arm moved the 126 g turbine pod 157 mm aft on deployment,
    shifting the CG +12.9 mm (7.1 % MAC) and dropping static margin from
    20 % to 13 % at the moment the turbine extends. A mast that only
    translates vertically shifts it by nothing, keeps the rotor axis aligned
    with the flow through the whole travel, and makes deployment depth a
    continuous variable.
    Sizing (tools/mast.py, new):
    - Stroke is 128 mm and is set by the rotor alone: radius + body
    clearance + stowed package. Stage count, station and fuselage depth
    do not change it.
    - 128 mm of travel cannot fit a single sliding mast inside a 73 mm deep
    fuse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
    [ff1_deployed.obj, ff1_deployed.stl, ff1_stowed.obj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]
2026-09-06 Correct the turbine analysis: harvest is net positive over a soaring cycle
    The previous framing led with "a turbine cannot extend endurance", which is
    only true for steady level flight. This aircraft soars: it climbs on
    atmospheric energy and descends on the turbine, so the source is the air,
    not the pack, and the output is net positive. Worse, the old text quoted
    Mode B per-descent (0.5 Wh) and never converted it to a rate, which made a
    real contribution look trivial.
    Replaces the "soar duty cycle" fudge in simulate() with a physical model.
    At each step the atmosphere offers f*(w - s_circle) of specific climb; if
    that beats what the airframe needs to stay up, the motor stays off and the
    su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
    [analysis.py]
2026-09-12 Add flight log analysis: graphs, fitted drag polar, predictions
    Takes an ArduPilot .BIN, an ArduPilot text .log, or any CSV, and writes a
    self-contained HTML report. Stdlib only, so it runs at the flying field
    without an install.
    - tools/flightlog.py .BIN (self-describing FMT parser), .log and CSV
    readers; fuzzy column matching onto a canonical
    channel set; uniform resampling that refuses to
    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
    [example_flight.csv]
2026-09-26 Add printable 1:1 build plans, tiled for A4
    tools/plans.py emits a 22-sheet A4 PDF of the airframe at exact full size --
    wing planform, FF-SC1 aerofoil templates at four chords, fuselage pod side
    and plan, formers, V-tail -- plus DXF outlines for CNC hot-wire or laser.
    Scale correctness is the whole job, so it is verified rather than assumed:
    page box is exactly 210x297 mm, the drawing transform is 2.834646 pt/mm, and
    100 drawing units land at 100.00001 mm on paper. All 22 sheets carry a 100 mm
    calibration bar, because print dialogs default to "fit to page" and quietly
    take 4-6 % off, which would move the CG.
    tools/pdf.py is a minimal vector PDF writer (paths, dashes, greys, base-14
    Helvet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
    [aerofoil_128mm.dxf, aerofoil_160mm.dxf, aerofoil_195mm.dxf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]
2026-09-26 Add materials list to the plans, fix core mass and boom length
    Two numbers in the plan disagreed with its own geometry:
    - wing core mass was 112 g against the 4.28 litres the aerofoil actually
    encloses at 30 kg/m3, which is 128 g
    - the boom length was computed to the V-tail leading edge rather than its
    trailing edge, so it was 140 mm short of supporting the tail
    Target mass moves 817 -> 833 g; predicted stall 5.5 -> 5.6 m/s, L/D and
    minimum sink unchanged.
    docs/PLANS.md now carries quantities taken from the plan geometry, the XPS
    vs EPS vs EPP choice, the solvent incompatibility that destroys polystyrene
    builds, and why the wing skin is load-bearing on the drag prediction.
    Co-Authored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
2026-09-26 Add a wing construction sheet and template index marks
    The planform sheets do not say how the aerofoil is produced, so someone could
    reasonably print them, cut round the outline and end up with a flat plate.
    New sheet 10 shows the hot-wire setup: the wire spans two end templates and
    sweeps a ruled surface between them, so the section comes from the template
    sheets and the planform is the plan-view check and marking guide.
    Every aerofoil template now carries numbered index marks at 5/10/20/30/45/60/
    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
    [howtocut.dxf]
2026-10-05 Add plans-based airframe variants at two spans
    Four 3D models matching what the printed plans actually produce: no
    retractable motor pylon and no retractable turbine mast, so the dorsal spine
    and keel fairing go too -- they exist only to swallow the retracting pods.
    glider-2000 2.0 m, no motor
    motor-2000 2.0 m, nose folding prop
    glider-2500 2.5 m, no motor
    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
    [glider-2000.obj, glider-2000.stl, glider-2500.obj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]
2026-10-05 Restore the solar array to the variants and add control-surface panel lines
    The variants dropped the wing solar array, which was my own call and not
    something that followed from removing the retractable pods. Put back.
    Also adds scribed hinge lines on the ailerons, flaps and ruddervators, upper
    and lower surfaces, with end ribs -- surface-conforming strips rather than a
    boolean cut, since cutting would make the wing non-manifold for no visual
    gain. The variants are now the full FF-1 model minus the two retractable pods
    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
    [ff1_deployed.obj, ff1_deployed.stl, ff1_stowed.obj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]
2026-10-05 Add JW-1, a swept flying wing in the Jetwing configuration
    planeprint.com is blocked by this session's egress policy (403 on CONNECT),
    so none of their published figures were available and a photo does not give
    geometry. This is a flying wing designed from scratch to the configuration in
    the photo -- swept tapered wing, upturned winglets, single dorsal fin, pusher
    prop on a blended pod -- with the tailless trim actually solved.
    The interesting part is that a tailless wing has to balance its own pitching
    moment:
    - Reflex is solved by bisection against thin-aerofoil theory to hit a target
    Cm(c/4). The implementation is validated against NACA 4412, returning
    alpha_L0 = -4.15 deg against a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
    [jetwing-1200.obj, jetwing-1200.stl, jetwing-1500.obj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]
2026-10-05 Add VT-1, a thrust-vectoring tail in the propeller slipstream
    A control surface in free air makes force proportional to V^2, so authority
    collapses exactly when it is most needed: hand launch, climb-out, a botched
    thermal entry. A vane in the pusher's slipstream makes force proportional to
    the jet speed instead, which stays high when the aircraft is slow. At 6 m/s
    on full throttle the jet carries 6.3x the free-stream dynamic pressure, and
    the vanes beat the elevons 1.9x on pitch while adding the yaw control the
    JW-1 never had.
    Layout: twin carbon booms outside the slipstream tube so they carry load
    without paying jet drag, a cruciform on the thrust axis inside the jet, the
    rudder kept to th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
    [jetwing-1200-vt.obj, jetwing-1200-vt.stl, jetwing-1500-vt.obj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]
2026-10-05 Add a basic plane built in Blender, and revert the vectoring tail
    Reverts the VT-1 twin-boom cruciform work, returning the Jetwing to a
    single fin.
    Adds blender/basic_plane.py: a simple conventional trainer -- fuselage,
    high wing with dihedral, tailplane, fin, undercarriage and a propeller --
    built parametrically from a dictionary of millimetre dimensions at the top
    of the file. Nine named objects in one collection, each with a material,
    Mirror modifiers left unapplied so they stay editable, and subdivision on
    the curved bodies.
    Two helpers carry it: loft() joins rings into a tube and plate() returns a
    rounded section, so swapping plate() for a NACA generator turns every
    surface into a rea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
    [basic_plane.blend, jetwing-1200-vt.obj, jetwing-1200-vt.stl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]
2026-10-08 Add the Jetwing flying wing in Blender, with working control surfaces
    A swept flying wing at the 2060 mm BIG WING span, built parametrically:
    reflexed NACA section with washout so it trims without a tailplane,
    upturned canted winglets, a blended EDF fuselage with side inlets and a
    nozzle, and a single fin whose rudder sits behind the nozzle -- which is
    what the kit calls integrated vector control.
    The four flaps and the rudder are separate objects whose origins sit on
    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
    [jetwing.blend]
2026-10-08 Add the fixed 50 mm EDF, shaped for efficiency rather than for thrust
    Models the propulsion as a permanent, fully faired installation: bellmouth
    inlets, a gentle diffuser, a 12-blade rotor, a 7-vane stator, motor can
    with a closing tailcone, and a converging nozzle. Nothing retracts.
    Sizing comes from tools/edf.py rather than from eyeballing, and the
    governing number is unflattering: at 16 m/s a 50 mm fan throws a 72 m/s
    jet, 4.5x flight speed, so Froude efficiency caps at 36% and the real
    figure is 22.6%. That is what a small fan on a slow aircraft is, and the
    70 mm unit the kit specifies is more efficient because it moves twice the
    air at a much lower jet speed. The design work is in not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
    [jetwing.blend]
2026-10-08 Optimise the wing by lifting line, and verify the built mesh against it
    The wing had a 94.4 mm tip, which puts the outboard sections at Reynolds
    48,700 at best-glide speed -- below about 55,000 a low-Re aerofoil's drag
    rises sharply and it stops reaching the lift it was designed around. The
    quoted L/D of 19.6 was a number the aircraft could not have delivered.
    tools/optimise.py solves the span loading properly, by lifting-line theory,
    because induced drag depends on how lift is spread across the span and a
    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
    [jetwing.blend]
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2026-10-08 Commit the printable STLs so they can be sliced without running Blender
    33 parts, 3.3 MB. Regenerable with blender/print_parts.py, but there is no
    reason to make someone install Blender to get at them.
    Claude-Session: https://claude.ai/code/session_01Xmbifyz4dWSGPwFYMDAxfC
    [aileron_L1.stl, aileron_L2.stl, aileron_L3.stl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]
2026-10-08 Add jetwing-parts.blend: all 33 printable parts in one file
    Opening 33 separate STLs to look at them is miserable, so they now come as
    one .blend: each part rotated onto the face it prints on, dropped to z = 0,
    laid out on a grid and labelled with its name and size, with an A1 build
    volume drawn alongside. The assembled aircraft sits in its own collection,
    hidden, for reference.
    Two things worth recording because both were silent:
    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
    [jetwing-parts.blend]
2026-10-08 Add the build manual, and repair tools/jetwing.py
    docs/ASSEMBLY.md: CG, carbon list, print settings, wing and fuselage
    assembly, hinges, throws in millimetres at the trailing edge, balance,
    pre-flight checks and the first flight. Every number is computed from the
    current geometry rather than carried over -- CG 318 mm from the nose
    (231 mm aft of the root leading edge), neutral point only 14.5 mm behind
    it, stall 7.5 m/s, thrust/weight 0.72.
    The manual leads with the CG and says to set it 10 mm nose-heavy for the
    first flight, because on a tailless aircraft that number is the difference
    between an aeroplane and an accident, and a static margin of 14.5 mm does
    not leave room for opinion.
    Als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
2026-10-10 Print servo bays, pushrod guides, loom channels and hatches into the wing
    Four bays, one per control surface, cut into the lower skin with a matching
    printed hatch. 37 parts now, all still inside the A1 and all watertight.
    Two findings drove the layout:
    A 9 g servo mounted the usual way up needs 22.7 mm of section depth and
    this wing does not have it anywhere. Laid on its side with the output
    shaft SPANWISE it needs 11.8 mm, the arm then sweeps in a chordwise
    plane and drives the surface directly.
    Even so it does not fit under the control surfaces: at the hinge line
    there is 11-15 mm of section against the 14.8 mm a 9 g needs with
    sensible walls. So the bays sit at 45% chord, just aft of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
    [hatch_aileron_L.stl, hatch_aileron_R.stl, hatch_flap_L.stl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]
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
